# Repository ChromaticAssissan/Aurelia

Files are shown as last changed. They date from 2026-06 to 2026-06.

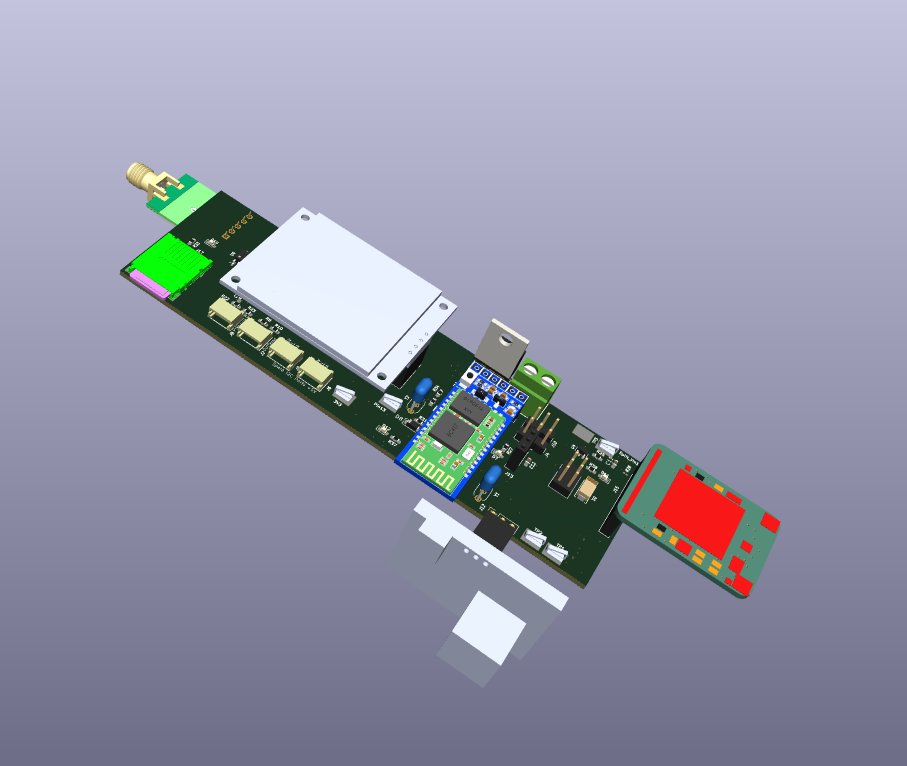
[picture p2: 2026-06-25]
Aurelia_Motherboard_9.png

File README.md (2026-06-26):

HEAD
\# Aurelia Upper Ocean Profiler

A custom variable buoyancy ocean profiling system developed at UMass Dartmouth.

\## Features

\- Arduino-based motherboard

\- Sensor integration

\- Wireless communication

\- Variable buoyancy control

\- Custom PCB development

\## Author

Frankie Bouchard

=======
# Aurelia
The design of the control boards for the Aurelia ocean profilier
2aa0dd996f78106de7114200720a692faca2b326

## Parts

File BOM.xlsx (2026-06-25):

Refrence | Qty | Value | Footprint | Price Per | Total Price | Link
C1,C2,C4,C5,C6,C7,C11,C12,C13,C15,C16,C17,C18,C19 | 50 | 100n | Capacitor_SMD:C_0603_1608Metric_Pad1.08x0.95mm_HandSolder | $0.15 | $7.75 | https://www.digikey.com/en/products/detail/samsung-electro-mechanics/CL10E104KC8VPNC/20498486
C3,C8,C9 | 50 | 1u | Capacitor_SMD:C_0603_1608Metric_Pad1.08x0.95mm_HandSolder | $0.03 | $1.25 | https://www.digikey.com/en/products/detail/samsung-electro-mechanics/CL10B105KO8NNNC/3886677
C10 | 5 | EDC334Z5R5H | Aurelia Library:SUP_CAP_EECSD_H_PAN | $3.52 | $17.60 | https://www.digikey.com/en/products/detail/cornell-dubilier-knowles/EDC334Z5R5H/10412861
C14 | 50 | 22p | Capacitor_SMD:C_0603_1608Metric_Pad1.08x0.95mm_HandSolder | $0.05 | $2.50 | https://www.digikey.com/en/products/detail/kemet/C0603C220J5GACTU/411055
D1 | 10 | 40V 3A | Aurelia Library:40V_3A_SMA_SHKY_DIODE | $0.34 | $3.45 | https://www.digikey.com/en/products/detail/diodes-incorporated/B340AE-13/7352831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
D2 | 10 | SMF24A | Diode_SMD:D_SMF | $0.16 | $1.64 | https://www.digikey.com/en/products/detail/diotec-semiconductor/SMF24A/13163858
D3,D8 | 10 | 100V 150mA | Diode_SMD:D_SOD-123 | $0.11 | $1.08 | https://www.digikey.com/en/products/detail/diotec-semiconductor/BAT46W/13156682
D4,D9,D11 | 50 | GREEN | LED_SMD:LED_0603_1608Metric_Pad1.05x0.95mm_HandSolder | $0.06 | $3.20 | https://www.digikey.com/en/products/detail/liteon/LTST-C190KGKT/386815
D5,D10 | 50 | RED | LED_SMD:LED_0603_1608Metric_Pad1.05x0.95mm_HandSolder | $0.06 | $3.20 | https://www.digikey.com/en/products/detail/liteon/LTST-C190KRKT/386817
D6 | 10 | 1N4448WS | Diode_SMD:D_SOD-323F | $0.10 | $1.04 | https://www.digikey.com/en/products/detail/onsemi/1N4448WS/1873806
D7 | 20 | BLUE | LED_SMD:LED_0603_1608Metric_Pad1.05x0.95mm_HandSolder | $0.16 | $3.20 | https://www.digikey.com/en/products/detail/w%C3%BCrth-elektronik/150060BS75000/4489895
D12 | 20 | YELLOW | LED_SMD:LED_0603_1608Metric_Pad1.05x0.95mm_HandSolder | $0.07 | $1.40 | https://www.digikey.com/en/products/detail/liteon/LTST-C190KSKT/386819
FB1 | 10 | 150R@100MHz | Resistor_SMD:R_0805_2012Metric_Pad1.20x1.40mm_HandSolder | $0.06 | $0.58 | https://www.digikey.com/en/products/detail/abracon-llc/ACML-0805-151-T/4696700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
J1 | 10 | USB4216-03-A | MotherboardLibrary:GCT_USB4216-03-A_REVA | $0.54 | $5.40 | https://www.digikey.com/en/products/detail/gct/USB4216-03-A/26598207
J2,J8 | 4 | Conn_01x04_Socket | Aurelia Library:DF13_4P_125DS_25 | $0.54 | $2.16 | https://www.digikey.com/en/products/detail/hirose-electric-co-ltd/DF13-4P-1-25DS-25/15997350
J3,J16 | 12 | Conn_02x03_Odd_Even | Connector_PinHeader_2.54mm:PinHeader_2x03_P2.54mm_Vertical | $0.12 | $1.44 | https://www.digikey.com/en/products/detail/oupiin/2011-2X03G00SD025B/13251540
J5 | 10 | Conn_01x03_Pin | Connector_PinHeader_2.54mm:PinHeader_1x03_P2.54mm_Vertical | $0.26 | $2.60 | https://www.digikey.com/en/products/detail/adam-tech/PH1-20-UA/9830398
J6,J9,J11 | 50 | Conn_01x04_Socket | Connector_JST:JST_XA_S04B-XASK-1N-BN_1x04_P2.50mm_Horizontal | $0.26 | $12.85 | https://www.digikey.com/en/products/detail/hirose-electric-co-ltd/DF1BZ-4P-2-5DS/1033131
J4,J10,J12,J13,J14,J15,J18 | 15 | Conn_01x20_Socket | Connector_PinSocket_2.54mm:PinSocket_1x04_P2.54mm_Vertical | $0.88 | $13.20 | https://www.digikey.com/en/products/detail/w%C3%BCrth-elektronik/61302011821/16608603
J7 | 10 | 9.6Vin | MotherboardLibrary:691137710002 | $0.35 | $3.54 | https://www.digikey.com/en/products/detail/w%C3%BCrth-elektronik/691137710002/6644051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
J17 | 5 | Micro_SD_Card | Connector_Card:microSD_HC_Hirose_DM3BT-DSF-PEJS | $2.52 | $12.60 | https://www.digikey.com/en/products/detail/hirose-electric-co-ltd/DM3BT-DSF-PEJS/1982749
R1,R4 | 10 | 5.1k | Resistor_SMD:R_0603_1608Metric_Pad0.98x0.95mm_HandSolder | $0.10 | $1.00 | https://www.digikey.com/en/products/detail/yageo/RC0603FR-075K1L/727268
R2,R3,R5,R6,R8,R10,R14,R15,R16,R17,R18,R19,R20,R22,R23,R25,R33,R36,R37 | 19 | 1k | Resistor_SMD:R_0603_1608Metric_Pad0.98x0.95mm_HandSolder | $0.10 | $1.90 | https://www.digikey.com/en/products/detail/stackpole-electronics-inc/RMCF0603FT1K00/1761077
R7,R21 | 20 | 210 | Resistor_SMD:R_0603_1608Metric_Pad0.98x0.95mm_HandSolder | $0.10 | $2.00 | https://www.digikey.com/en/products/detail/panasonic-industry/ERJ-3EKF2100V/196213
R9,R30 | 20 | 1M | Resistor_SMD:R_0603_1608Metric_Pad0.98x0.95mm_HandSolder | $0.10 | $2.00 | https://www.digikey.com/en/products/detail/yageo/RC0201FR-071ML/3202390
R11,R24,R27,R28,R31 | 20 | 10k | Resistor_SMD:R_0603_1608Metric_Pad0.98x0.95mm_HandSolder | $0.10 | $2.00 | https://www.digikey.com/en/products/detail/yageo/RC0201FR-071ML/3202390
R12,R13 | 20 | 22 | Resistor_SMD:R_0603_1608Metric_Pad0.98x0.95mm_HandSolder | $0.10 | $2.00 | https://www.digikey.com/en/products/detail/panasonic-industry/ERA-3AEB223V/1465886 | https://www.digikey.com/en/products/detail/panasonic-industry/ERA-3AEB223V/1465886
R26 | 20 | 4k7 | Resistor_SMD:R_0603_1608Metric_Pad0.98x0.95mm_HandSolder | $0.10 | $2.00 | https://www.digikey.com/en/products/detail/yageo/RC0603FR-0747KL/727253
R29 | 20 | 680 | Resistor_SMD:R_0603_1608Metric_Pad0.98x0.95mm_HandSolder | $0.10 | $2.00 | https://www.digikey.com/en/products/detail/panasonic-industry/ERJ-3EKF6800V/413159
R32 | 20 | 220 | Resistor_SMD:R_0603_1608Metric_Pad0.98x0.95mm_HandSolder | $0.10 | $2.00 | https://www.digikey.com/en/products/detail/panasonic-industry/ERJ-3EKF2200V/1746334
R34,R35 | 20 | 4.7k | Resistor_SMD:R_0603_1608Metric_Pad0.98x0.95mm_HandSolder | $0.10 | $2.00 | https://www.digikey.com/en/products/detail/stackpole-electronics-inc/RMCF0603FT4K70/1760998
U1,U5 | 25 | PCA9306DC1Z | Package_SO:VSSOP-8_2.3x2mm_P0.5mm | $0.74 | $18.40 | https://www.digikey.com/en/products/detail/nxp-usa-inc/PCA9306DC1Z/26226838
U2,U11 | 25 | LM321 | Package_TO_SOT_SMD:SOT-23-5 | $0.05 | $1.37 | https://www.digikey.com/en/products/detail/shenzhen-slkormicro-semicon-co-ltd/LM321/21852988
U3 | 10 | ATmega16U2-A | Package_QFP:TQFP-32_7x7mm_P0.8mm | $3.24 | $32.40 | https://www.digikey.com/en/products/detail/microchip-technology/ATMEGA16U2-MU/2050821
U4 | 10 | FDN340P | Package_TO_SOT_SMD:SOT-23 | $0.40 | $3.95 | https://www.digikey.com/en/products/detail/onsemi/FDN340P/965304
U6 | 10 | LP2985-3.3 | Package_TO_SOT_SMD:SOT-23-5_HandSoldering | $0.38 | $3.82 | https://www.digikey.com/en/products/detail/texas-instruments/LP2985-33DBVR/809759
U7 | 10 | LM7805CV | Package_TO_SOT_THT:TO-220-3_Vertical | $0.76 | $7.55 | https://www.digikey.com/en/products/detail/stmicroelectronics/L7805CV/585964
U8 | 2 | RYLR998(RF) | Connector_PinSocket_2.54mm:PinSocket_1x05_P2.54mm_Horizontal | $11.80 | $23.60 | https://www.digikey.com/en/products/detail/reyax/RYLR998/22078252
U9 | 10 | CD4050BPWR | Package_SO:SOIC-16_3.9x9.9mm_P1.27mm | $0.44 | $4.37 | https://www.digikey.com/en/products/detail/texas-instruments/CD4050BDR/1691133
U10 | 10 | ATmega2560-16A | Package_QFP:TQFP-100_14x14mm_P0.5mm | $21.67 | $216.70 | https://www.digikey.com/en/products/detail/microchip-technology/ATMEGA2560-16AU/735455
Y1,Y2 | 25 | 16MHz | Crystal:Resonator_Murata_CSTLSxxxX-3Pin_W5.5mm_H3.0mm | $0.27 | $6.79 | https://www.digikey.com/en/products/detail/murata-electronics/CSTLS16M0X54-A0/13250850
O1 | 4 | HC-06 | Bluetooth Module | $4.25 | $16.99 | https://www.amazon.com/ACEIRMC-Wireless-Bluetooth-Transceiver-Bi-Directional/dp/B08L8KN9Z6?s=electronics
 |  |  |  | Total | $456.52

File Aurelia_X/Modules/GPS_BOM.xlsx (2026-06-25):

GPS
Description | amount | package | cost | link
RF reciever | 1 | qen-20 | $24.95 | https://www.digikey.com/en/products/detail/adafruit-industries-llc/790/5353682
SCHEMATIC | https://cdn-learn.adafruit.com/assets/assets/000/109/800/original/adafruit_products_UltimateGPS_USBC_sch.png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
pinout for the adifruit ultimate gps breakout - 66 channel w/10Hz updates
GPS Pin | ATmega2560 Pin / Label | Purpose / Notes for Schematic
VIN | +5 V from Mega (pin 5 V header) | Powers the GPS module through its onboard regulator. Label this as 5V.
GND | GND | Common ground between the Mega and GPS. Tie to the same ground net.
TX | RX1 / Pin 19 / PH0 | GPS transmit line → Mega receive. Label the GPS TX net as GPS_TX → RX1 (Pin 19 Arduino Mega). | https://devboards.info/boards/arduino-mega2560-rev3 / https://cdn-learn.adafruit.com/downloads/pdf/adafruit-ultimate-gps.pdf
RX | TX1 / Pin 18 / PH1 | Mega transmit line → GPS receive. Label as GPS_RX ← TX1 (Pin 18 Arduino Mega).
VBAT (or VBACKUP) | Optional CR1220 battery (+ to VBAT, – to GND) | Keeps the GPS’s internal RTC and almanac for faster fix (“hot start”). You can also tie VBAT to 3.3 V if you don’t plan to add a coin cell.
EN | Leave unconnected (or pull HIGH to 3.3 V) | Enables module. Pull LOW to shut down the GPS for low-power mode. Normally leave floating or tied HIGH.
PPS (1PPS) | Optional → any digital input (e.g. Pin 2) | Outputs a 1 Hz pulse once the GPS has a valid fix. Label as GPS_PPS → D2.
FIX | Optional → LED or input (e.g. Pin 3) | Logic HIGH = GPS fix acquired. Often drives an LED through a 1 kΩ resistor. Label as GPS_FIX → D3.

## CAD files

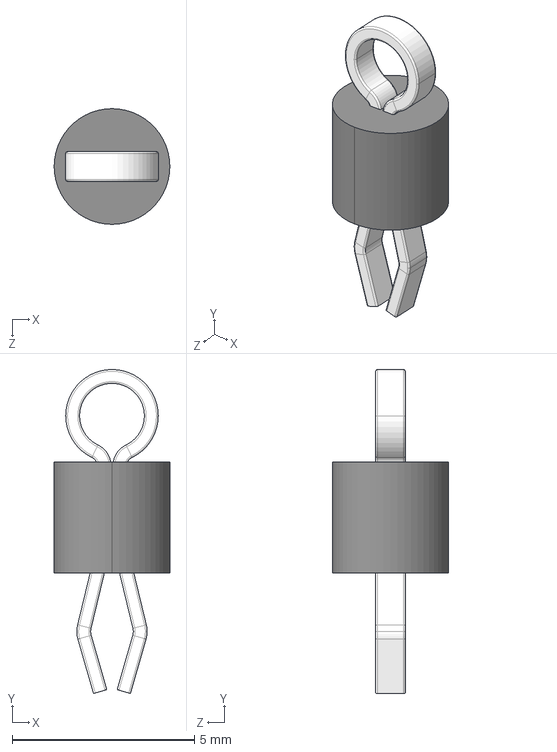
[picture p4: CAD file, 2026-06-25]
Aurelia_X/5006/5006.step
3.17 x 8.89 x 3.17 mm

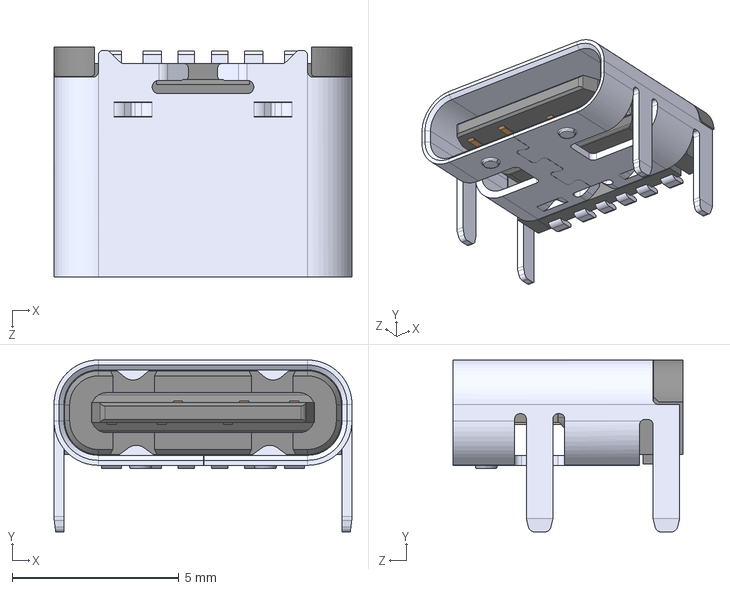
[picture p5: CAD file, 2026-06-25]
Aurelia_X/2171750001/2171750001.step
8.94 x 5.16 x 6.90 mm

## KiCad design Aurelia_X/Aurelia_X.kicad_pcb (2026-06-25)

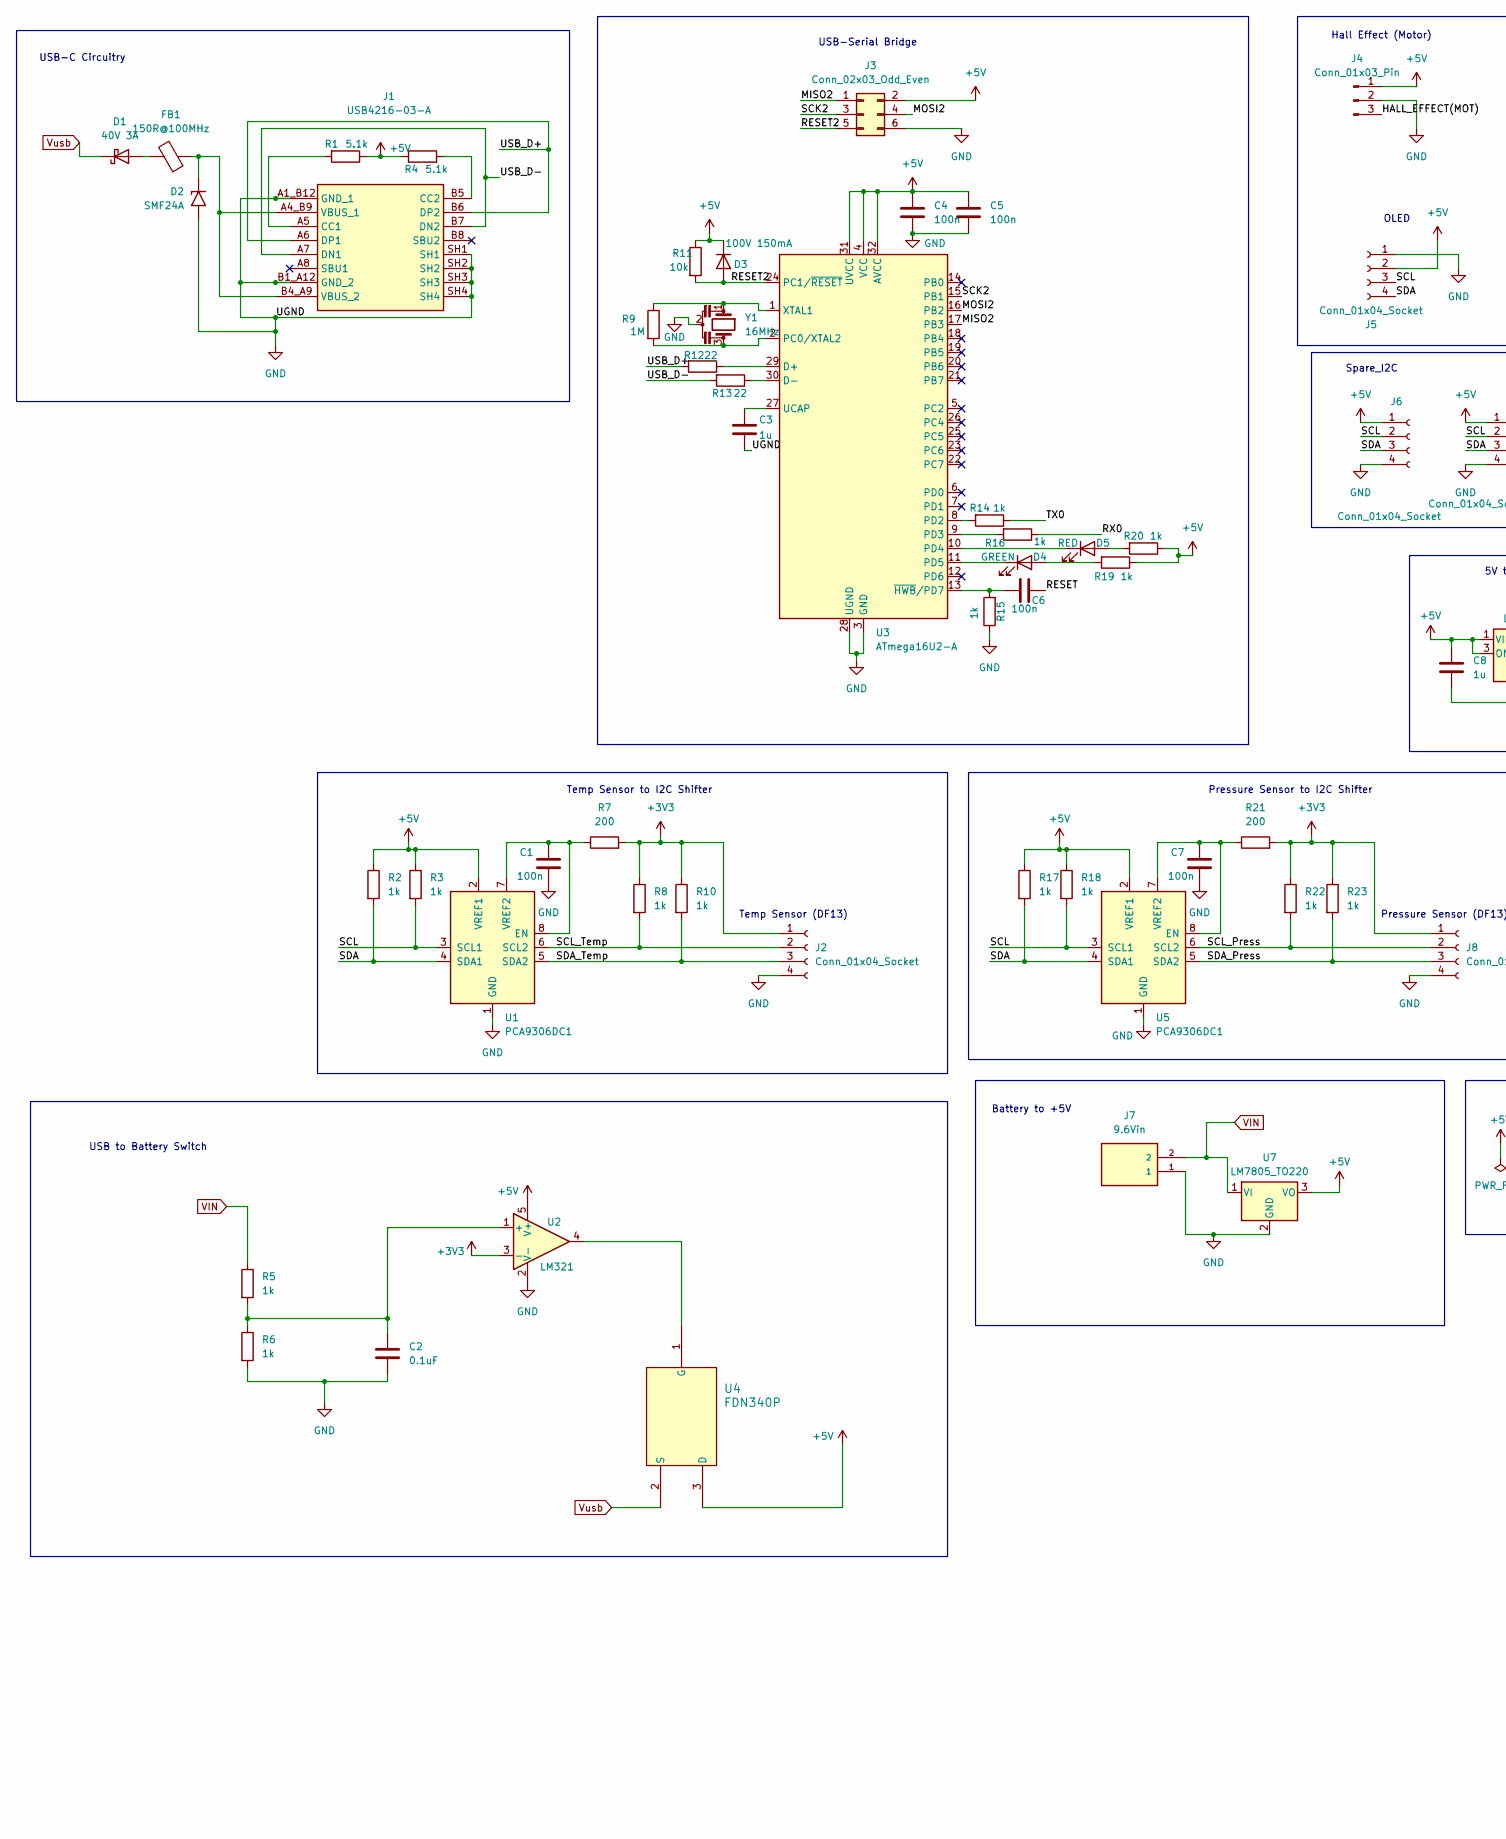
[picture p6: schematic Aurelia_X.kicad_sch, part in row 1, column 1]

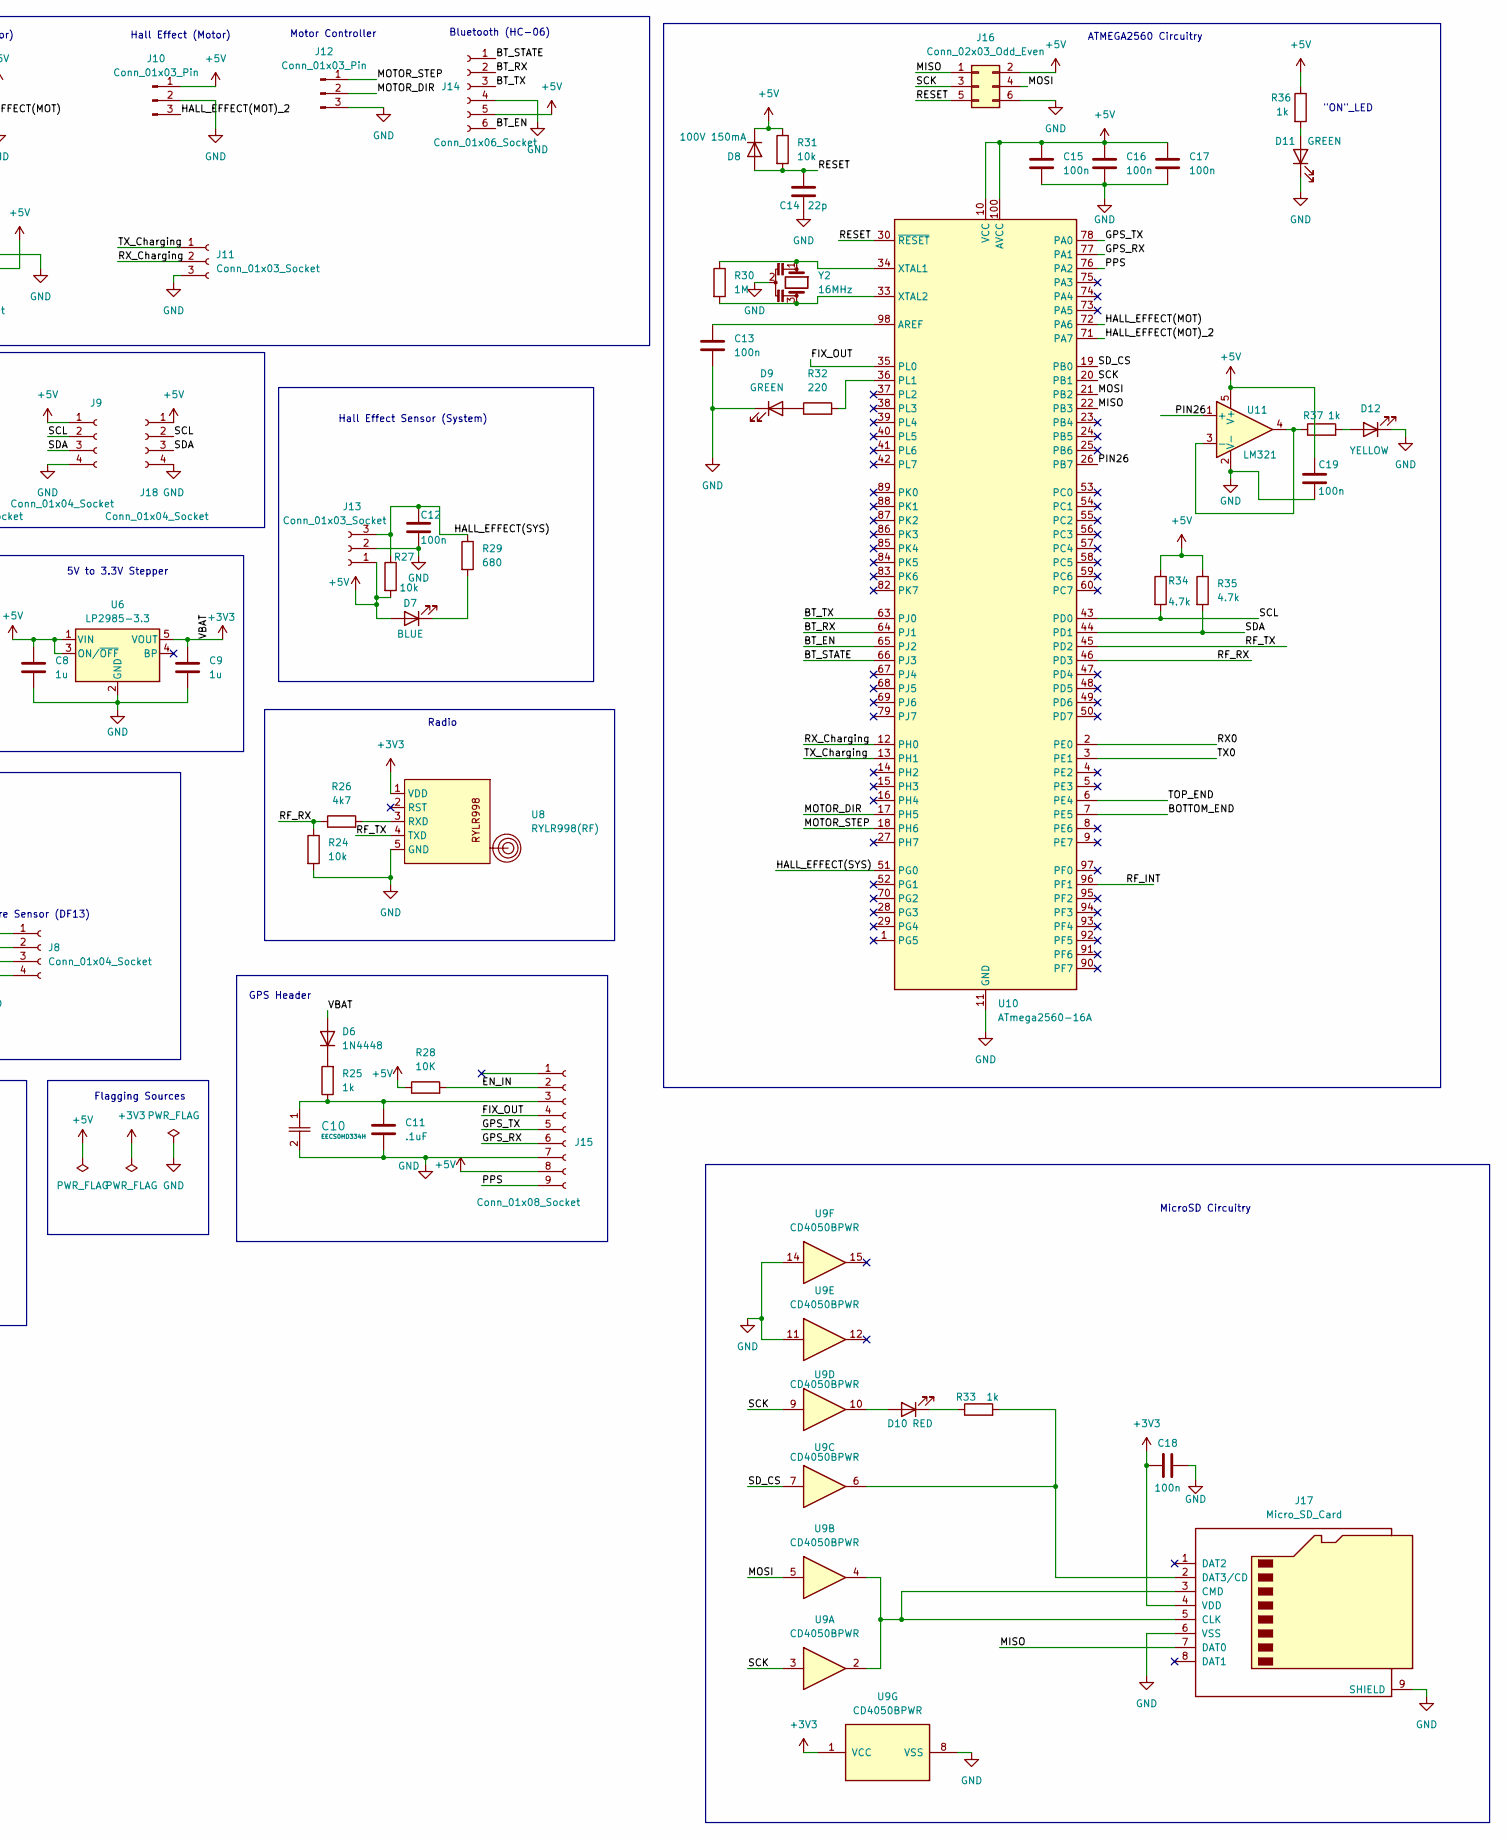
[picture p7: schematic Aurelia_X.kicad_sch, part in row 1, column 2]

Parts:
C1, C4, C5, C6, C7, C12, C13, C15, C16, C17, C18, C19: 100n; C_0603_1608Metric_Pad1.08x0.95mm_HandSolder
C2: 0.1uF; C_0603_1608Metric_Pad1.08x0.95mm_HandSolder
C3, C8, C9: 1u; C_0603_1608Metric_Pad1.08x0.95mm_HandSolder
C10: EECS0HD334H; SUP_CAP_EECSD_H_PAN
C11: .1uF; C_0603_1608Metric_Pad1.08x0.95mm_HandSolder
C14: 22p; C_0603_1608Metric_Pad1.08x0.95mm_HandSolder
D1: 40V 3A; 40V_3A_SMA_SHKY_DIODE
D2: SMF24A; D_SMF
D3, D8: 100V 150mA; D_SOD-123
D4, D9, D11: GREEN; LED_0603_1608Metric_Pad1.05x0.95mm_HandSolder
D5, D10: RED; LED_0603_1608Metric_Pad1.05x0.95mm_HandSolder
D6: 1N4448; D_SOD-323F
D7: BLUE; LED_0603_1608Metric_Pad1.05x0.95mm_HandSolder
D12: YELLOW; LED_0603_1608Metric_Pad1.05x0.95mm_HandSolder
FB1: 150R@100MHz; R_0805_2012Metric_Pad1.20x1.40mm_HandSolder
J1: USB4216-03-A; GCT_USB4216-03-A_REVA; Mouser Part Number 640-USB4216-03-A
J2, J8: Conn_01x04_Socket; DF13_4P_125DS_25
J3, J16: Conn_02x03_Odd_Even; PinHeader_2x03_P2.54mm_Vertical
J4, J10, J12: Conn_01x03_Pin; PinHeader_1x03_P2.54mm_Vertical
J5: Conn_01x04_Socket; PinSocket_1x04_P2.54mm_Vertical
J6, J9, J18: Conn_01x04_Socket; JST_XA_S04B-XASK-1N-BN_1x04_P2.50mm_Horizontal
J7: 9.6Vin; 691137710002
J11: Conn_01x03_Socket; PinHeader_1x03_P2.54mm_Vertical
J13: Conn_01x03_Socket; PinSocket_1x03_P2.54mm_Vertical
J14: Conn_01x06_Socket; PinSocket_1x06_P2.54mm_Vertical
J15: Conn_01x08_Socket; PinSocket_1x09_P2.54mm_Vertical
J17: Micro_SD_Card; microSD_HC_Hirose_DM3BT-DSF-PEJS
R1, R4: 5.1k; R_0603_1608Metric_Pad0.98x0.95mm_HandSolder
R2, R3, R5, R6, R8, R10, R14, R15, R16, R17, R18, R19, R20, R22, R23, R25, R33, R36, R37: 1k; R_0603_1608Metric_Pad0.98x0.95mm_HandSolder
R7, R21: 200; R_0603_1608Metric_Pad0.98x0.95mm_HandSolder
R9, R30: 1M; R_0603_1608Metric_Pad0.98x0.95mm_HandSolder
R11, R24, R27, R31: 10k; R_0603_1608Metric_Pad0.98x0.95mm_HandSolder
R12, R13: 22; R_0603_1608Metric_Pad0.98x0.95mm_HandSolder
R26: 4k7; R_0603_1608Metric_Pad0.98x0.95mm_HandSolder
R28: 10K; R_0603_1608Metric_Pad0.98x0.95mm_HandSolder
R29: 680; R_0603_1608Metric_Pad0.98x0.95mm_HandSolder
R32: 220; R_0603_1608Metric_Pad0.98x0.95mm_HandSolder
R34, R35: 4.7k; R_0603_1608Metric_Pad0.98x0.95mm_HandSolder
U1, U5: PCA9306DC1; VSSOP-8_2.3x2mm_P0.5mm
U2, U11: LM321; SOT-23-5
U3: ATmega16U2-A; TQFP-32_7x7mm_P0.8mm
U4: FDN340P; SOT-23
U6: LP2985-3.3; SOT-23-5_HandSoldering
U7: LM7805_TO220; TO-220-3_Vertical
U8: RYLR998(RF); PinSocket_1x05_P2.54mm_Horizontal
U9: CD4050BPWR; SOIC-16_3.9x9.9mm_P1.27mm
U10: ATmega2560-16A; TQFP-100_14x14mm_P0.5mm
Y1, Y2: 16MHz; Resonator_Murata_CSTLSxxxX-3Pin_W5.5mm_H3.0mm

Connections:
+3V3: C9.1, C18.1, D6.2 (A), J2.1, J8.1, J17.4 (VDD), R7.2, R8.1, R10.1, R21.2, R22.1, R23.1, U2.3 (-), U6.5 (VOUT), U8.1 (VDD), U9.1 (VCC)
+5V: C4.1, C5.1, C8.1, C15.1, C16.1, C17.1, C19.1, D3.1 (K), D7.2 (A), D8.1 (K), J3.2, J4.1, J5.2, J6.1, J9.1, J10.1, J13.1, J14.5, J15.8, J16.2, J18.1, R1.1, R2.1, R3.1, R4.1, R11.1, R17.1, R18.1, R19.1, R20.1, R27.2, R28.1, R31.1, R34.1, R35.1, R36.1, U1.2 (VREF1), U2.5 (V+), U3.4 (VCC), U3.31 (UVCC), U3.32 (AVCC), U4.3 (D), U5.2 (VREF1), U6.1 (VIN), U6.3 (ON/~OFF), U7.3 (VO), U10.10 (VCC), U10.31 (VCC), U10.61 (VCC), U10.80 (VCC), U10.100 (AVCC), U11.5 (V+)
/BOTTOM_END: U10.7 (PE5)
/BT_EN: J14.6, U10.65 (PJ2)
/BT_RX: J14.2, U10.64 (PJ1)
/BT_STATE: J14.1, U10.66 (PJ3)
/BT_TX: J14.3, U10.63 (PJ0)
/EN_IN: J15.2, R28.2
/FIX_OUT: J15.4, U10.35 (PL0)
/GPS_RX: J15.6, U10.77 (PA1)
/GPS_TX: J15.5, U10.78 (PA0)
/HALL_EFFECT(MOT): J4.3, U10.72 (PA6)
/HALL_EFFECT(MOT)_2: J10.3, U10.71 (PA7)
/HALL_EFFECT(SYS): C12.1, J13.3, R27.1, R29.1, U10.51 (PG0)
/MISO: J16.1, J17.7 (DAT0), U10.22 (PB3)
/MISO2: J3.1, U3.17 (PB3)
/MOSI: J16.4, U9.5, U10.21 (PB2)
/MOSI2: J3.4, U3.16 (PB2)
/MOTOR_DIR: J12.2, U10.17 (PH5)
/MOTOR_STEP: J12.1, U10.18 (PH6)
/PIN26: U10.26 (PB7), U11.1 (+)
/PPS: J15.9, U10.76 (PA2)
/RESET: C6.1, C14.1, D8.2 (A), J16.5, R31.2, U10.30 (~RESET)
/RESET2: D3.2 (A), J3.5, R11.2, U3.24 (PC1/~RESET)
/RF_INT: U10.96 (PF1)
/RF_RX: R24.1, R26.1, U10.46 (PD3)
/RF_TX: U8.4 (TXD), U10.45 (PD2)
/RX0: R16.1, U10.2 (PE0)
/RX_Charging: J11.2, U10.12 (PH0)
/SCK: J16.3, U9.3, U9.9, U10.20 (PB1)
/SCK2: J3.3, U3.15 (PB1)
/SCL: J5.3, J6.2, J9.2, J18.2, R3.2, R18.2, R34.2, U1.3 (SCL1), U5.3 (SCL1), U10.43 (PD0)
/SCL_Press: J8.2, R22.2, U5.6 (SCL2)
/SCL_Temp: J2.2, R8.2, U1.6 (SCL2)
/SDA: J5.4, J6.3, J9.3, J18.3, R2.2, R17.2, R35.2, U1.4 (SDA1), U5.4 (SDA1), U10.44 (PD1)
/SDA_Press: J8.3, R23.2, U5.5 (SDA2)
/SDA_Temp: J2.3, R10.2, U1.5 (SDA2)
/SD_CS: U9.7, U10.19 (PB0)
/TOP_END: U10.6 (PE4)
/TX0: R14.1, U10.3 (PE1)
/TX_Charging: J11.1, U10.13 (PH1)
/USB_D+: J1.A6 (DP1), J1.B6 (DP2), R12.2
/USB_D-: J1.A7 (DN1), J1.B7 (DN2), R13.2
GND: C1.2, C2.2, C3.2, C4.2, C5.2, C7.2, C8.2, C9.2, C10.2, C11.2, C12.2, C13.2, C14.2, C15.2, C16.2, C17.2, C18.2, C19.2, D2.2 (A2), D9.1 (K), D11.1 (K), D12.1 (K), J1.A1_B12 (GND_1), J1.B1_A12 (GND_2), J1.SH1, J1.SH2, J1.SH3, J1.SH4, J2.4, J3.6, J4.2, J5.1, J6.4, J7.1, J8.4, J9.4, J10.2, J11.3, J12.3, J13.2, J14.4, J15.7, J16.6, J17.6 (VSS), J17.9 (SHIELD), J18.4, R6.2, R15.1, R24.2, U1.1 (GND), U2.2 (V-), U3.3 (GND), U3.28 (UGND), U5.1 (GND), U6.2 (GND), U7.2 (GND), U8.5 (GND), U9.8 (VSS), U9.11, U9.14, U10.11 (GND), U10.32 (GND), U10.62 (GND), U10.81 (GND), U10.99 (GND), U11.2 (V-), Y1.2, Y2.2
unnamed: D1.2 (A), FB1.2
unnamed: D2.1 (A1), FB1.1, J1.A4_B9 (VBUS_1), J1.B4_A9 (VBUS_2)
unnamed: D4.2 (A), R19.2
unnamed: D4.1 (K), U3.11 (PD5)
unnamed: D5.2 (A), R20.2
unnamed: D5.1 (K), U3.10 (PD4)
unnamed: D6.1 (K), R25.2
unnamed: D7.1 (K), R29.2
unnamed: D9.2 (A), R32.1
unnamed: D10.2 (A), U9.10
unnamed: D10.1 (K), R33.1
unnamed: D11.2 (A), R36.2
unnamed: D12.2 (A), R37.2
unnamed: J1.A5 (CC1), R1.2
unnamed: J1.B5 (CC2), R4.2
unnamed: C10.1, C11.1, J15.3, R25.1
unnamed: J17.3 (CMD), J17.5 (CLK), U9.2, U9.4
unnamed: J17.2 (DAT3/CD), R33.2, U9.6
unnamed: C1.1, R7.1, U1.7 (VREF2), U1.8 (EN)
unnamed: C2.1, R5.2, R6.1, U2.1 (+)
unnamed: R12.1, U3.29 (D+)
unnamed: R13.1, U3.30 (D-)
unnamed: R9.2, U3.2 (PC0/XTAL2), Y1.3
unnamed: R14.2, U3.8 (PD2)
unnamed: R16.2, U3.9 (PD3)
unnamed: C3.1, U3.27 (UCAP)
unnamed: R9.1, U3.1 (XTAL1), Y1.1
unnamed: C6.2, R15.2, U3.13 (~HWB/PD7)
unnamed: U2.4, U4.1 (G)
unnamed: C7.1, R21.1, U5.7 (VREF2), U5.8 (EN)
unnamed: R26.2, U8.3 (RXD)
unnamed: C13.1, U10.98 (AREF)
unnamed: R32.2, U10.36 (PL1)
unnamed: R30.1, U10.34 (XTAL1), Y2.1
unnamed: R30.2, U10.33 (XTAL2), Y2.3
unnamed: R37.1, U11.3 (-), U11.4
VIN: J7.2, R5.1, U7.1 (VI)
Vusb: D1.1 (K), U4.2 (S)

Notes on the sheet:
Temp Sensor (DF13)
Spare_I2C
Radio
USB-C Circuitry
Bluetooth (HC-06)
Pressure Sensor to I2C Shifter
OLED
Hall Effect Sensor (System)
Flagging Sources
ATMEGA2560 Circuitry
Motor Controller
Hall Effect (Motor)
5V to 3.3V Stepper
Battery to +5V
Pressure Sensor (DF13)
"ON"_LED
USB to Battery Switch
Temp Sensor to I2C Shifter
GPS Header
USB-Serial Bridge
MicroSD Circuitry

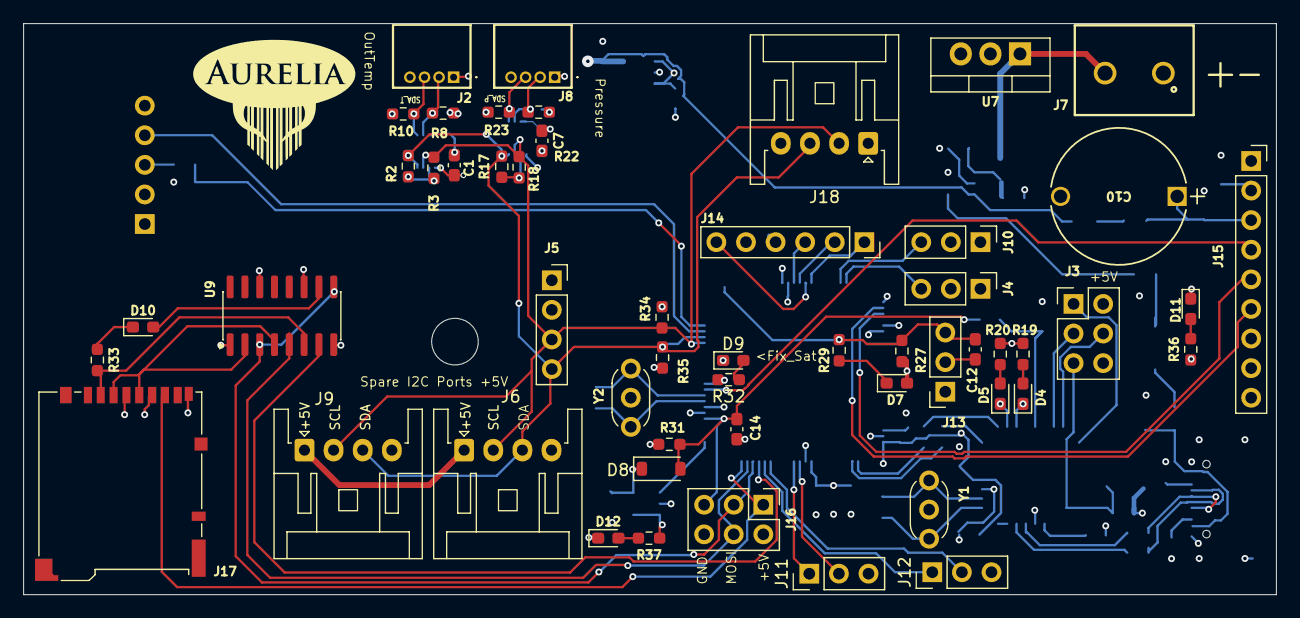
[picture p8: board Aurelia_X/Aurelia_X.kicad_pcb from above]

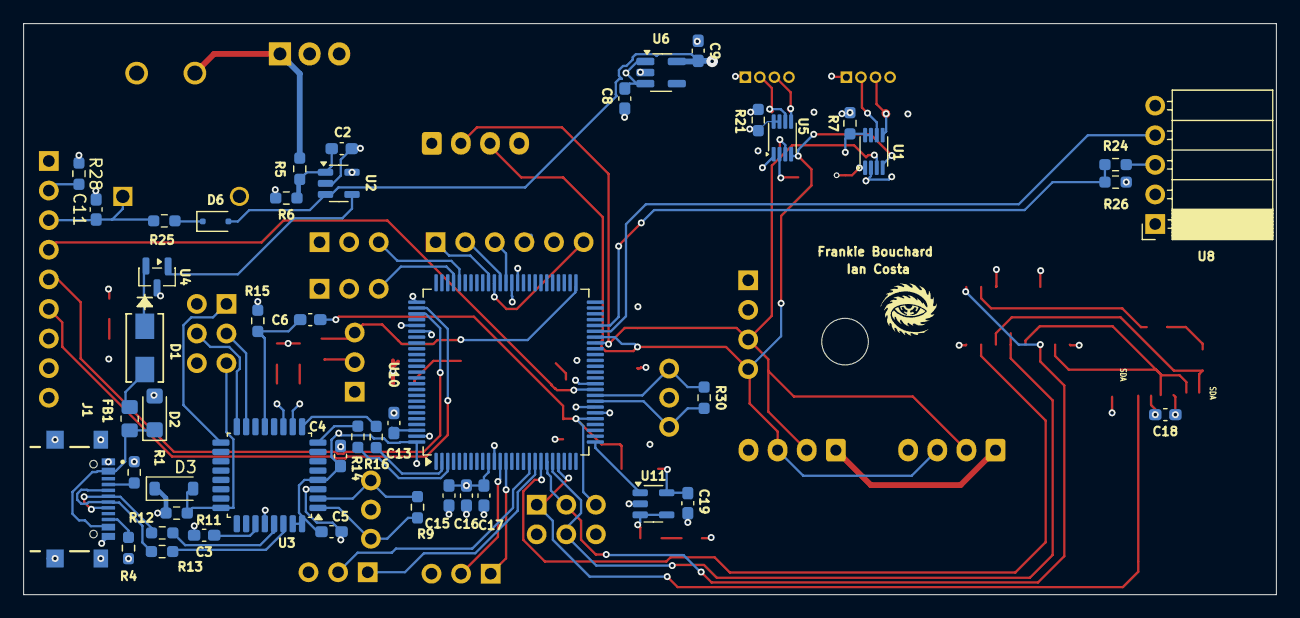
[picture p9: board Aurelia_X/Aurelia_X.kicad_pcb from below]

Board: 4 copper layers, 107.5 x 49.0 mm, 100 parts (47 on the bottom side), 79 nets.

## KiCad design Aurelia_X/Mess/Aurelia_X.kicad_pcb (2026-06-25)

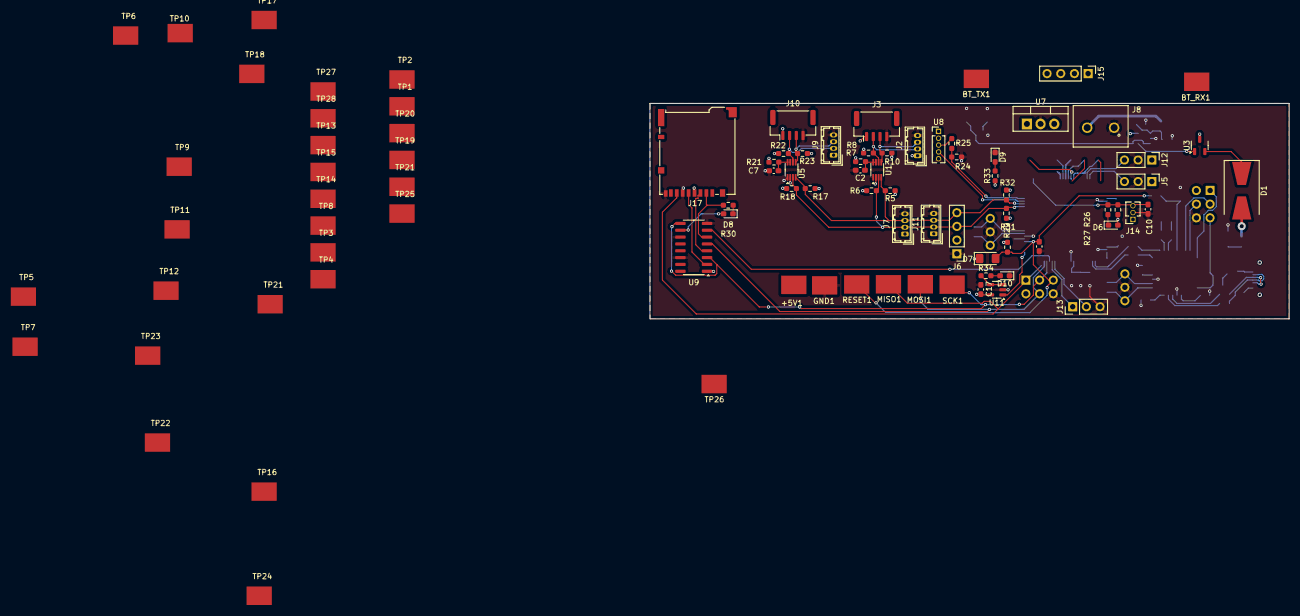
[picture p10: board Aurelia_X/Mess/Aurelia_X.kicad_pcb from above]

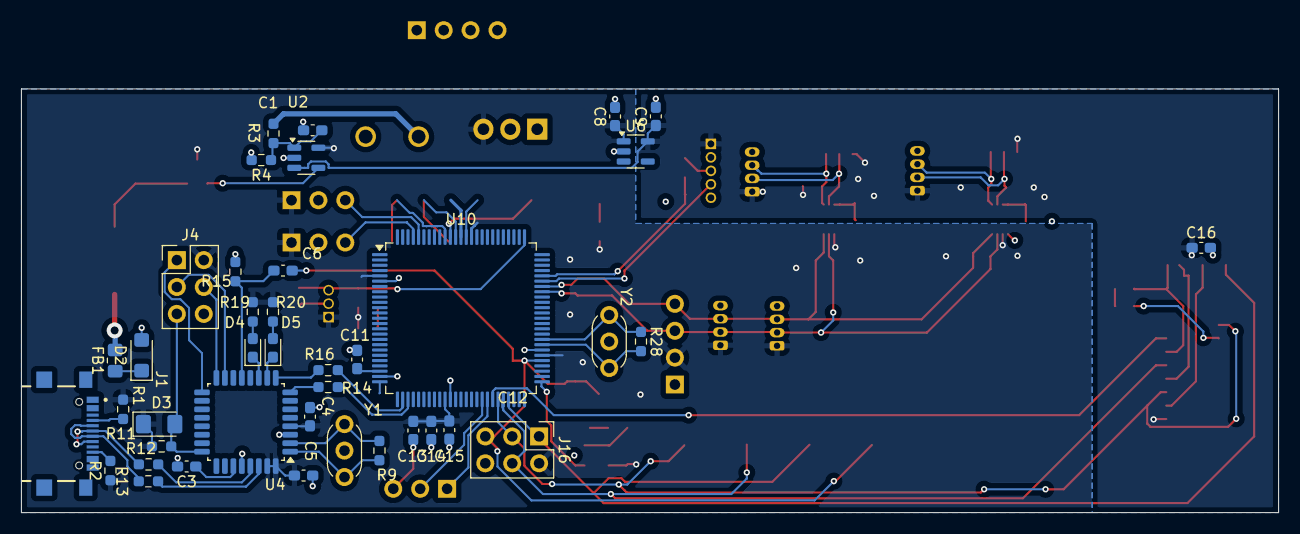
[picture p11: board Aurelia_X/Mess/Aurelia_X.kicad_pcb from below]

Board: 2 copper layers, 118.7 x 40.0 mm, 129 parts (40 on the bottom side), 72 nets.

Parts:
+5V1: 5018; TesPo_TP470X343
BT_RX1: 5018; TesPo_TP470X343
BT_TX1: 5018; TesPo_TP470X343
C1: 0.1uF; C_0603_1608Metric_Pad1.08x0.95mm_HandSolder
C2, C4, C5, C6, C7, C10, C11, C13, C14, C15, C16, C17: 100n; C_0603_1608Metric_Pad1.08x0.95mm_HandSolder
C3, C8, C9: 1u; C_0603_1608Metric_Pad1.08x0.95mm_HandSolder
C12: 22p; C_0603_1608Metric_Pad1.08x0.95mm_HandSolder
D1: 40V 3A; D_SMB-SMC_Universal_Handsoldering
D2: SMF24A; D_SMF
D3, D7: 100V 150mA; D_1206_3216Metric_Pad1.42x1.75mm_HandSolder
D4, D9: GREEN; LED_0603_1608Metric_Pad1.05x0.95mm_HandSolder
D5, D8: RED; LED_0603_1608Metric_Pad1.05x0.95mm_HandSolder
D6: BLUE; LED_0603_1608Metric_Pad1.05x0.95mm_HandSolder
D10: YELLOW; LED_0603_1608Metric_Pad1.05x0.95mm_HandSolder
FB1: 150R@100MHz; R_0805_2012Metric_Pad1.20x1.40mm_HandSolder
GND1: 5018; TesPo_TP470X343
J1: USB4216-03-A; GCT_USB4216-03-A_REVA
J2, J7, J9, J11: Conn_01x04_Socket; Hirose_DF13-04P-1.25DSA_1x04_P1.25mm_Vertical
J3, J10: Conn_01x04_Socket; JST_GH_BM04B-GHS-TBT_1x04-1MP_P1.25mm_Vertical
J4, J16: Conn_02x03_Odd_Even; PinHeader_2x03_P2.54mm_Vertical
J5, J12, J13: Conn_01x03_Pin; PinHeader_1x03_P2.54mm_Vertical
J6, J15: Conn_01x04_Socket; PinHeader_1x04_P2.54mm_Vertical
J8: 9.6Vin; 691137710002
J14: Conn_01x03_Socket; PinSocket_1x03_P1.27mm_Vertical
J17: Micro_SD_Card; microSD_HC_Hirose_DM3BT-DSF-PEJS
MISO1: 5018; TesPo_TP470X343
MOSI1: 5018; TesPo_TP470X343
R1, R2: 5.1k; R_0603_1608Metric_Pad0.98x0.95mm_HandSolder
R3, R4, R5, R6, R8, R10, R14, R15, R16, R17, R18, R19, R20, R22, R23, R30, R33, R34: 1k; R_0603_1608Metric_Pad0.98x0.95mm_HandSolder
R7, R21: 200; R_0603_1608Metric_Pad0.98x0.95mm_HandSolder
R9, R28: 1M; R_0603_1608Metric_Pad0.98x0.95mm_HandSolder
R11, R24, R26, R29: 10k; R_0603_1608Metric_Pad0.98x0.95mm_HandSolder
R12, R13: 22; R_0603_1608Metric_Pad0.98x0.95mm_HandSolder
R25: 4k7; R_0603_1608Metric_Pad0.98x0.95mm_HandSolder
R27: 680; R_0603_1608Metric_Pad0.98x0.95mm_HandSolder
R31, R32: 4.7k; R_0603_1608Metric_Pad0.98x0.95mm_HandSolder
RESET1: 5018; TesPo_TP470X343
SCK1: 5018; TesPo_TP470X343
TP1, TP2, TP3, TP4, TP5, TP6, TP7, TP8, TP9, TP10, TP11, TP12, TP13, TP14, TP15, TP16, TP17, TP18, TP19, TP20, TP21, TP21#2, TP22, TP23, TP24, TP25, TP26, TP27, TP28: 5018; TesPo_TP470X343
U1, U5: PCA9306DC1; VSSOP-8_2.3x2mm_P0.5mm
U2, U11: LM321; SOT-23-5
U3: FDN340P; SOT-23-3
U4: ATmega16U2-A; TQFP-32_7x7mm_P0.8mm
U6: LP2985-3.3; SOT-23-5
U7: LM7805_TO220; TO-220-3_Vertical
U8: RYLR998(RF); PinHeader_1x05_P1.27mm_Vertical
U9: 4050; SOIC-16_3.9x9.9mm_P1.27mm
U10: ATmega2560-16A; TQFP-100_14x14mm_P0.5mm
Y1, Y2: 16MHz; Resonator_Murata_CSTLSxxxX-3Pin_W5.5mm_H3.0mm

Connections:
+3V3: C9.1, C16.1, J2.1, J3.1, J9.1, J10.1, J17.4 (VDD), R7.2, R8.1, R10.1, R21.2, R22.1, R23.1, TP15.TP, U2.3 (-), U6.5 (VOUT), U8.1 (VDD), U9.1 (VCC)
+5V: +5V1.TP, C4.1, C5.1, C8.1, C13.1, C14.1, C15.1, C17.1, D3.1 (K), D6.2 (A), D7.1 (K), J4.2, J5.1, J6.2, J7.1, J11.1, J12.1, J14.1, J15.4, J16.2, R1.1, R2.1, R5.1, R6.1, R11.1, R17.1, R18.1, R19.1, R20.1, R26.2, R29.1, R31.1, R32.1, R33.1, TP9.TP, TP13.TP, U1.2 (VREF1), U2.5 (V+), U3.3 (D), U4.4 (VCC), U4.31 (UVCC), U4.32 (AVCC), U5.2 (VREF1), U6.1 (VIN), U6.3 (ON/~OFF), U7.3 (VO), U10.10 (VCC), U10.31 (VCC), U10.61 (VCC), U10.80 (VCC), U11.5 (V+)
/BOTTOM_END: TP23.TP, U10.17 (PH5)
/BT_RX: BT_RX1.TP, J15.1, U10.44 (PD1)
/BT_TX: BT_TX1.TP, J15.2, U10.43 (PD0)
/GPS_RX: TP18.TP, U10.3 (PE1)
/GPS_TX: TP17.TP, U10.2 (PE0)
/HALL_EFFECT(MOT): J5.3, TP24.TP, U10.98 (AREF)
/HALL_EFFECT(MOT)_2: J12.3, TP25.TP
/HALL_EFFECT(SYS): C10.1, J14.3, R26.1, R27.1, TP16.TP, U10.97 (PF0)
/MISO: J16.1, J17.7 (DAT0), MISO1.TP, U10.38 (PL3)
/MISO2: J4.1, TP5.TP, U4.17 (PB3)
/MOSI: J16.4, MOSI1.TP, U9.5, U10.37 (PL2)
/MOSI2: J4.4, TP10.TP, U4.16 (PB2)
/MOTOR_DIR: J13.2, TP19.TP, U10.7 (PE5)
/MOTOR_STEP: J13.1, TP20.TP, U10.8 (PE6)
/PIN26: U10.42 (PL7), U11.1 (+)
/RESET: C6.1, C12.1, D7.2 (A), J16.5, R29.2, RESET1.TP, U10.78 (PA0)
/RESET2: D3.2 (A), J4.5, R11.2, TP6.TP, U4.24 (PC1/~RESET)
/RF_INT: TP21.TP, U10.52 (PG1)
/RF_RX: R24.1, R25.1, U10.66 (PJ3)
/RF_TX: U8.4 (TXD), U10.65 (PJ2)
/RX0: R16.1, TP12.TP, U10.12 (PH0)
/SCK: J16.3, SCK1.TP, U9.3, U9.9, U10.36 (PL1)
/SCK2: J4.3, TP7.TP, U4.15 (PB1)
/SCL: J6.3, J7.2, J11.2, R6.2, R18.2, R31.2, TP28.TP, U1.3 (SCL1), U5.3 (SCL1), U10.63 (PJ0)
/SCL_Press: J9.2, J10.2, R22.2, U5.6 (SCL2)
/SCL_Temp: J2.2, J3.2, R8.2, U1.6 (SCL2)
/SDA: J6.4, J7.3, J11.3, R5.2, R17.2, R32.2, TP27.TP, U1.4 (SDA1), U5.4 (SDA1), U10.64 (PJ1)
/SDA_Press: J9.3, J10.3, R23.2, U5.5 (SDA2)
/SDA_Temp: J2.3, J3.3, R10.2, U1.5 (SDA2)
/SD_CS: U9.7, U10.35 (PL0)
/TOP_END: TP22.TP, U10.16 (PH4)
/TX0: R14.1, TP11.TP, U10.13 (PH1)
/USB_D+: J1.A6 (DP1), J1.B6 (DP2), R12.2, TP2.TP
/USB_D-: J1.A7 (DN1), J1.B7 (DN2), R13.2, TP1.TP
GND: C1.2, C2.2, C3.2, C4.2, C5.2, C7.2, C8.2, C9.2, C10.2, C11.2, C12.2, C13.2, C14.2, C15.2, C16.2, C17.2, D2.2 (A2), D9.1 (K), D10.1 (K), GND1.TP, J2.4, J3.4, J4.6, J5.2, J6.1, J7.4, J8.1, J9.4, J10.4, J11.4, J12.2, J13.3, J14.2, J15.3, J16.6, J17.6 (VSS), J17.9 (SHIELD), R4.2, R15.1, R24.2, TP26.TP, U1.1 (GND), U2.2 (V-), U4.3 (GND), U4.28 (UGND), U5.1 (GND), U6.2 (GND), U7.2 (GND), U8.5 (GND), U9.8 (VSS), U9.11, U9.14, U10.11 (GND), U10.32 (GND), U10.62 (GND), U10.81 (GND), U10.99 (GND), U11.2 (V-), Y1.2, Y2.2
unnamed: D1.2 (A), FB1.2
unnamed: D2.1 (A1), FB1.1
unnamed: D4.2 (A), R19.2
unnamed: D4.1 (K), U4.11 (PD5)
unnamed: D5.2 (A), R20.2
unnamed: D5.1 (K), U4.10 (PD4)
unnamed: D6.1 (K), R27.2
unnamed: D8.2 (A), U9.10
unnamed: D8.1 (K), R30.1
unnamed: D9.2 (A), R33.2
unnamed: D10.2 (A), R34.2
unnamed: J1.A5 (CC1), R1.2
unnamed: J1.B5 (CC2), R2.2
unnamed: J17.5 (CLK), U9.2
unnamed: J17.3 (CMD), U9.4
unnamed: J17.2 (DAT3/CD), R30.2, U9.6
unnamed: C2.1, R7.1, U1.7 (VREF2), U1.8 (EN)
unnamed: C1.1, R3.2, R4.1, TP3.TP, U2.1 (+)
unnamed: TP8.TP, U2.4, U3.1 (G)
unnamed: R12.1, U4.29 (D+)
unnamed: R13.1, U4.30 (D-)
unnamed: R9.2, U4.2 (PC0/XTAL2), Y1.3
unnamed: R14.2, U4.8 (PD2)
unnamed: R16.2, U4.9 (PD3)
unnamed: C3.1, U4.27 (UCAP)
unnamed: R9.1, U4.1 (XTAL1), Y1.1
unnamed: C6.2, R15.2, U4.13 (~HWB/PD7)
unnamed: C7.1, R21.1, U5.7 (VREF2), U5.8 (EN)
unnamed: R25.2, U8.3 (RXD)
unnamed: R28.1, U10.76 (PA2), Y2.1
unnamed: R28.2, U10.74 (PA4), Y2.3
unnamed: C11.1, U10.72 (PA6)
unnamed: R34.1, U11.3 (-), U11.4
VIN: J8.2, R3.1, TP14.TP, U7.1 (VI)
Vusb: D1.1 (K), TP4.TP, U3.2 (S)

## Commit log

2026-05-26 Added Aurelia motherboard and charging board files
2026-06-25 Add completed Aurelia X KiCad Project
    [2171750001.step, 5006.step, Aurelia_X.kicad_pcb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]
